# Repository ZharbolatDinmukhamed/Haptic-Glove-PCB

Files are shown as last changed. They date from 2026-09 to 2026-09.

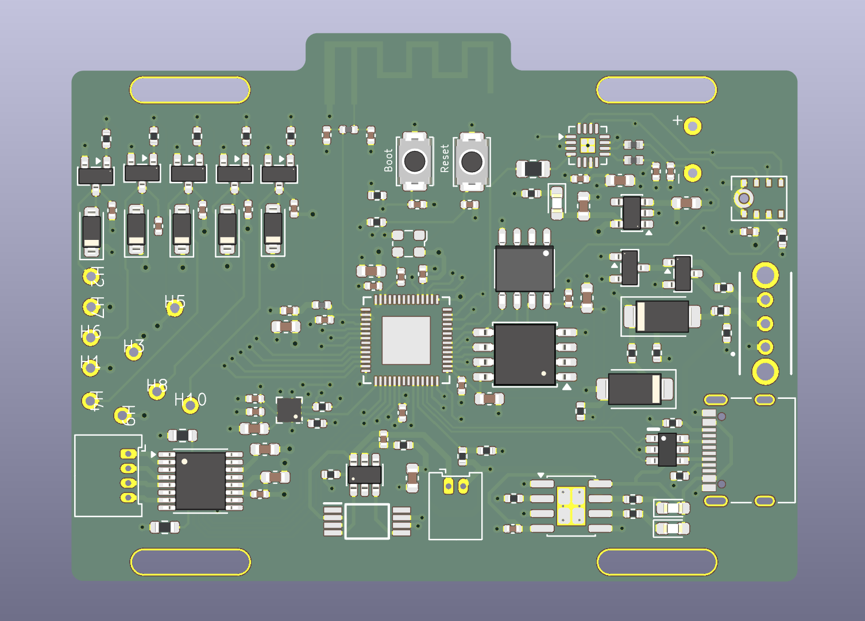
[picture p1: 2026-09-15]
Haptic Glove 3d view.png

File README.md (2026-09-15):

# Haptic Glove PCB

A wrist-mounted PCB for a haptic feedback glove, developed as part of my Research Assistantship at the Tactile Laboratory, Nazarbayev University.

## Overview
The board mounts on the wrist and drives 5 vibromotors, one per fingertip, delivering independent tactile feedback to each finger. It is designed to sit inside a glove, secured to the wrist via velcro straps threaded through slots in the board.

## Design Details
- **Board size:** 65mm x 50mm
- **Actuators:** 5x vibromotors (one per fingertip), each with a dedicated 3.3V power channel and signal channel
- **Driver components:** Capacitors and diodes placed near the board edge for each motor driver channel
- **Wrist-to-fingertip connection:** Discrete flexible wire harness (evaluated flex PCB / FPC, but chose a wire harness for flexibility and cost)
- **Mounting:** Component side faces outward (away from skin); board sits on the palm/volar side of the wrist inside the glove
- **Hand coverage:** Single-hand design

## Files
- `/schematic` — Schematic source files
- `/pcb` — PCB layout files
- `/gerbers` — Fabrication-ready Gerber files
- `/images` — Board renders and assembled photos
- `BOM.csv` — Bill of materials

## Tools
- [Your EDA tool — e.g. KiCad / Altium / Eagle]

## Status
[In progress / Fabricated & tested / etc. — update with current status]

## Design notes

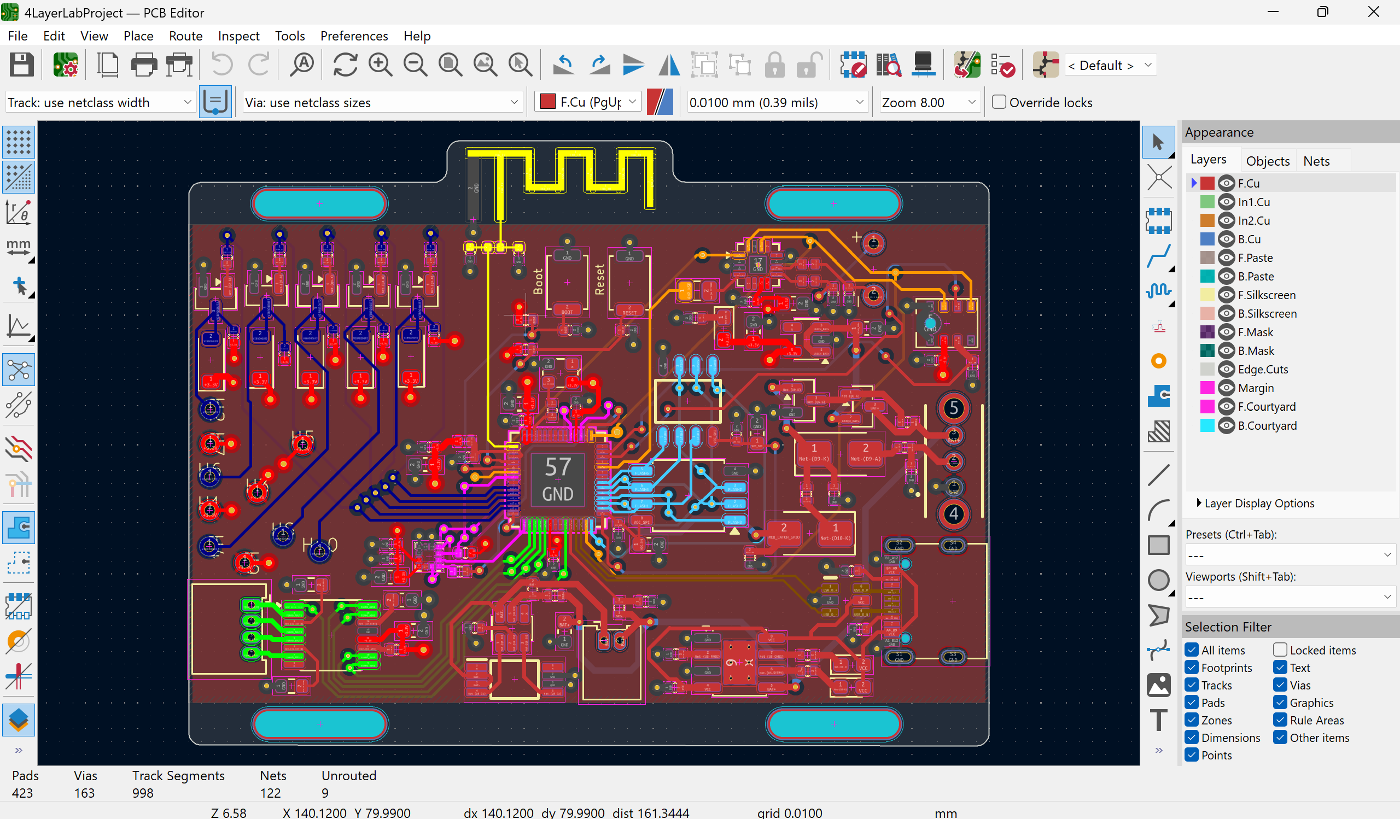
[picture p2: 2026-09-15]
Haptic Glove pcb view.png

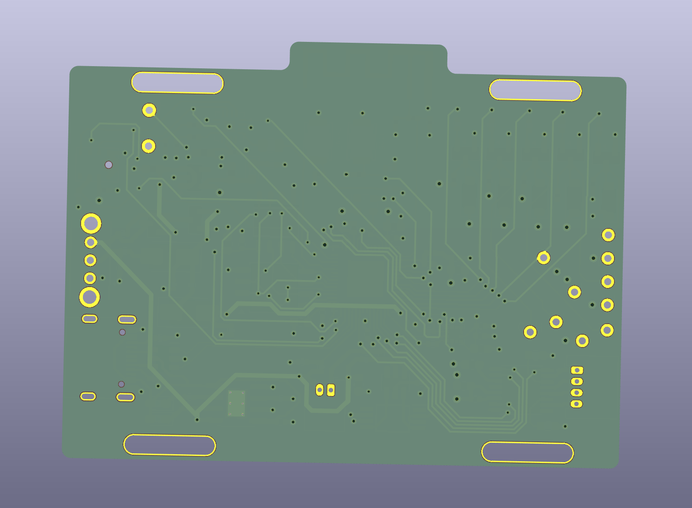
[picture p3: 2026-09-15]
Haptic Glove 3Dview.png

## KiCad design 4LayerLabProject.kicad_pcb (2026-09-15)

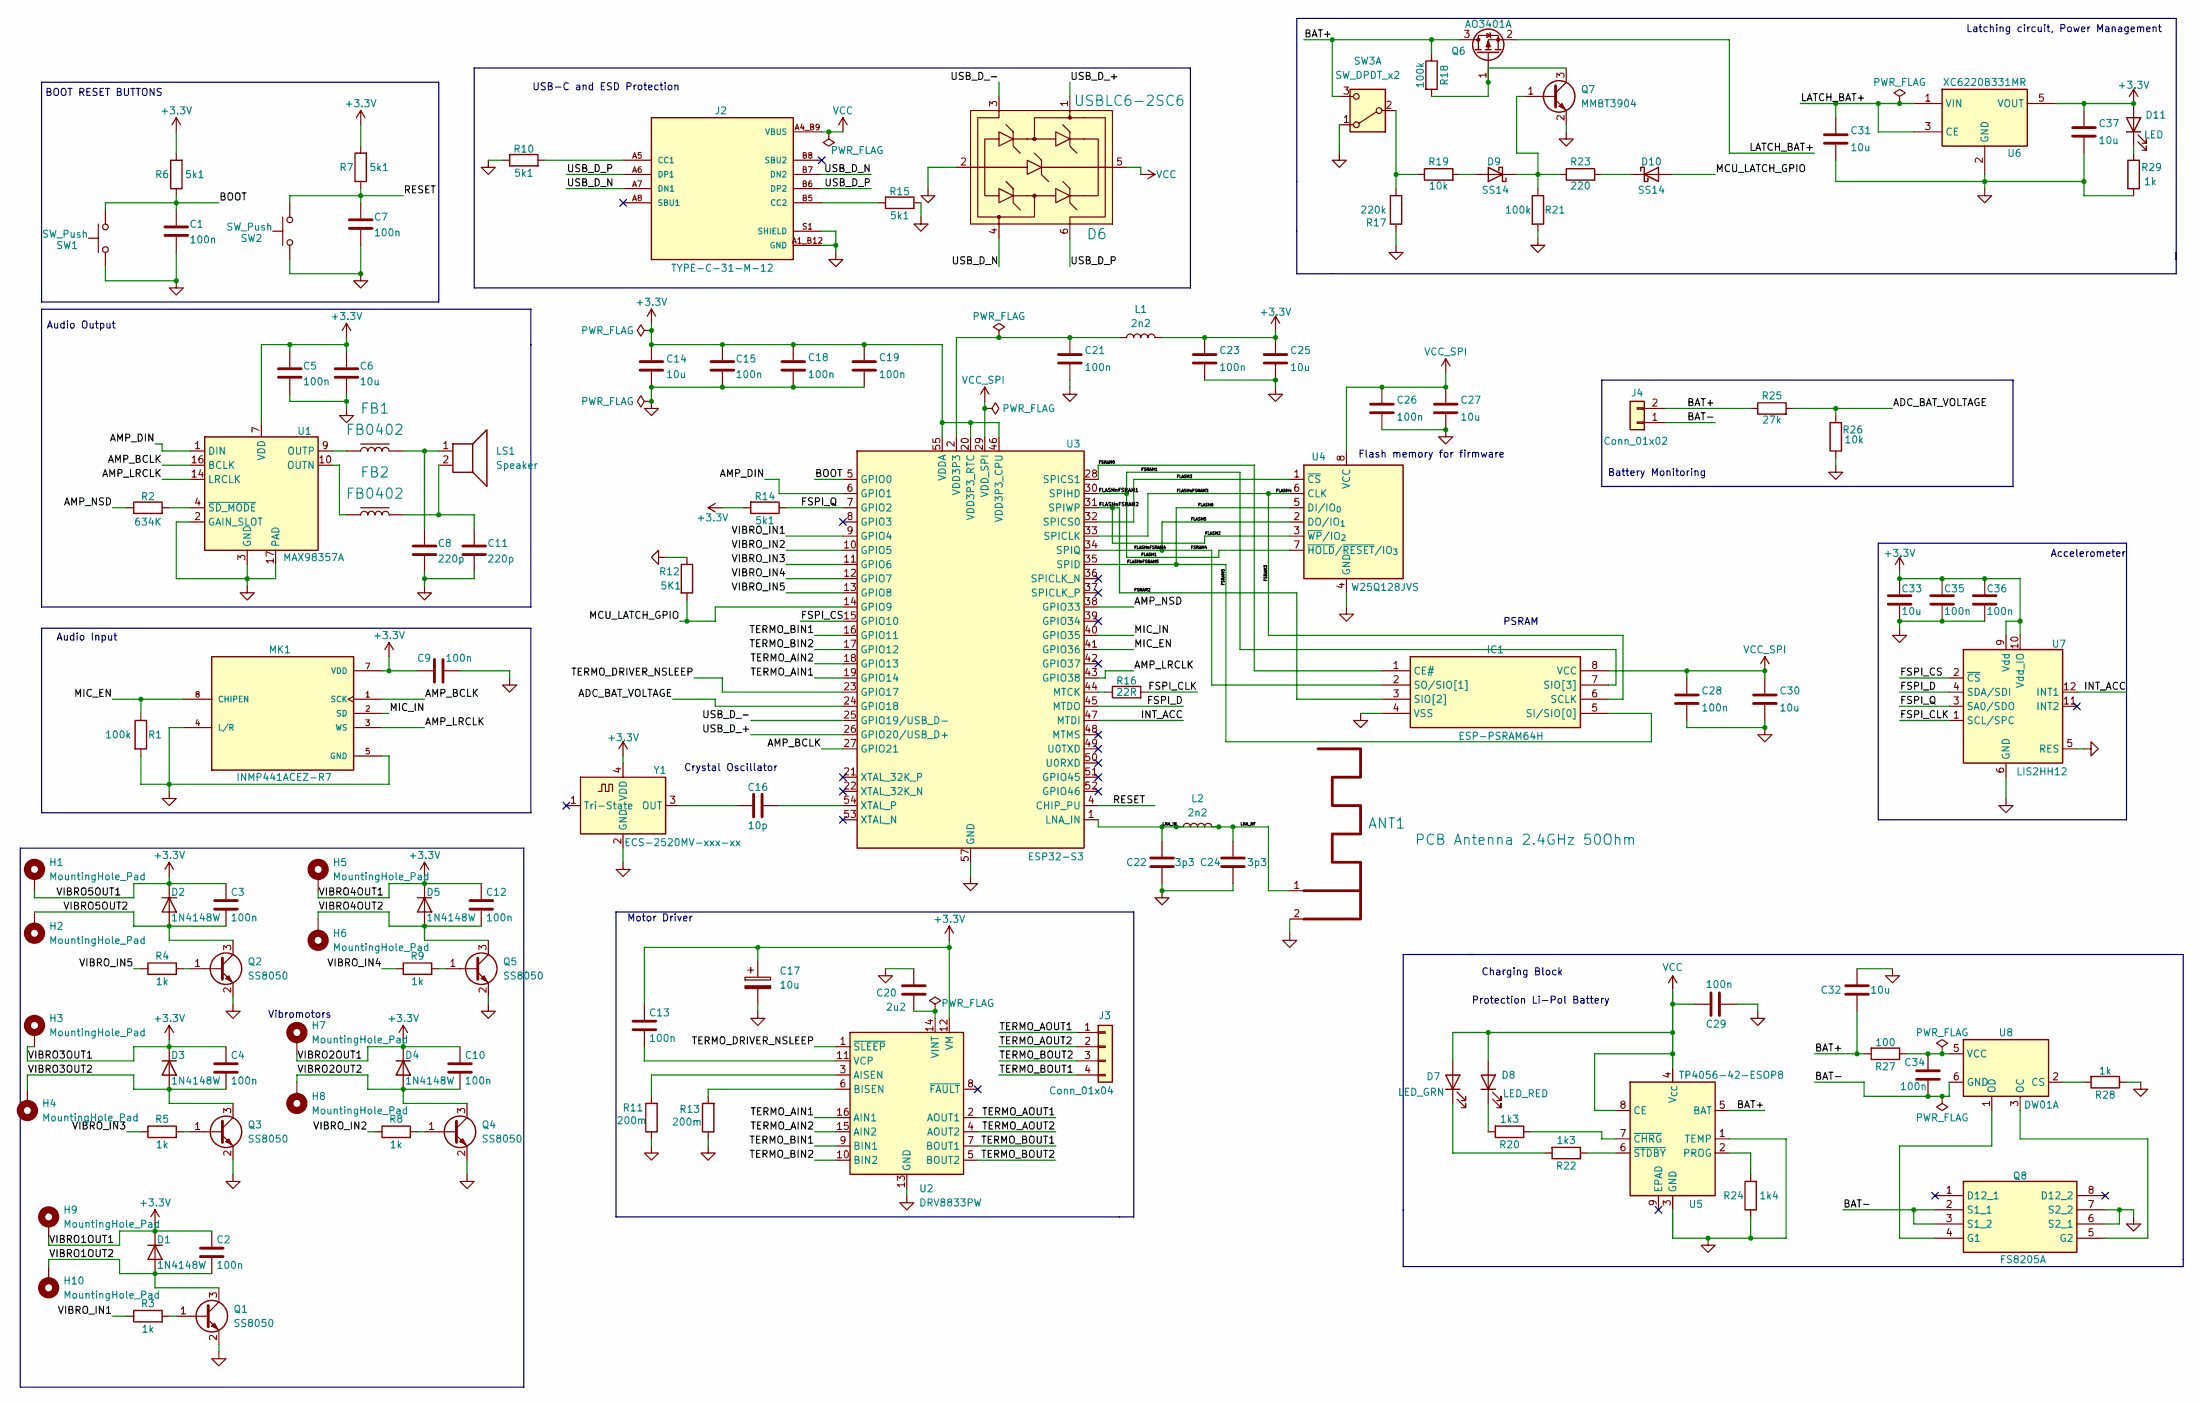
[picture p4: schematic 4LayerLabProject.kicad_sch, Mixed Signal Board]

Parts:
ANT1: PCB Antenna 2.4GHz 50Ohm; ANT_IFA_USB_2_4GHZ_50R
C1, C2, C3, C4, C5, C7, C9, C10, C12, C13, C15, C18, C19, C21, C23, C26, C28, C29, C34, C35, C36: 100n; C_0402_1005Metric
C6, C14, C17, C25, C27, C30, C31, C32, C33, C37: 10u; C_0603_1608Metric
C8, C11: 220p; C_0402_1005Metric
C16: 10p; C_0402_1005Metric
C20: 2u2; C_0603_1608Metric
C22, C24: 3p3; C_0402_1005Metric
D1, D2, D3, D4, D5: 1N4148W; D_SOD-123
D6: USBLC6-2SC6; SOT-23-6; Manufacturer Part Number USBLC6-2SC6
D7: LED_GRN; LED_0603_1608Metric_Pad1.05x0.95mm_HandSolder
D8: LED_RED; LED_0603_1608Metric_Pad1.05x0.95mm_HandSolder
D9, D10: SS14; D_SMA
D11: LED; LED_0603_1608Metric_Pad1.05x0.95mm_HandSolder
FB1, FB2: FB0402; FB_0402; Manufacturer Part Number *; LCSC *
H1, H2, H3, H4, H5, H6, H7, H8, H9, H10: MountingHole_Pad; tht_pad
IC1: ESP-PSRAM64H; SOIC127P600X175-8N; Manufacturer_Part_Number ESP-PSRAM64H
J2: TYPE-C-31-M-12; HRO_TYPE-C-31-M-12; PARTREV 2020.12.08
J3: Conn_01x04; Molex_PicoBlade_53048-0410_1x04_P1.25mm_Horizontal
J4: Conn_01x02; Molex_PicoBlade_53048-0210_1x02_P1.25mm_Horizontal
L1, L2: 2n2; L_0402_1005Metric
LS1: Speaker; Untitled_1
MK1: INMP441ACEZ-R7; MIC_INMP441ACEZ-R7; PARTREV 1.1
Q1, Q2, Q3, Q4, Q5: SS8050; SOT-23
Q6: AO3401A; SOT-23
Q7: MMBT3904; SOT-23
Q8: FS8205A; SOP65P640X120-8N; Manufacturer_Part_Number FS8205A
R1, R18, R21: 100k; R_0402_1005Metric
R2: 634K; R_0805_2012Metric
R3, R4, R5, R8, R9, R28, R29: 1k; R_0402_1005Metric
R6, R7, R10, R14, R15: 5k1; R_0402_1005Metric
R11, R13: 200m; R_0603_1608Metric
R12: 5K1; R_0402_1005Metric
R16: 22R; R_0402_1005Metric
R17: 220k; R_0402_1005Metric
R19, R26: 10k; R_0402_1005Metric
R20, R22: 1k3; R_0402_1005Metric
R23: 220; R_0402_1005Metric
R24: 1k4; R_0402_1005Metric
R25: 27k; R_0402_1005Metric
R27: 100; R_0402_1005Metric
SW1, SW2: SW_Push; SW_Push_SPST_NO_Alps_SKRK
SW3: SW_DPDT_x2; OS102011MA1QN1
U1: MAX98357A; TQFN-16-1EP_3x3mm_P0.5mm_EP1.23x1.23mm
U2: DRV8833PW; TSSOP-16_4.4x5mm_P0.65mm
U3: ESP32-S3; QFN56_7X7_EXP
U4: W25Q128JVS; SOIC-8_5.3x5.3mm_P1.27mm
U5: TP4056-42-ESOP8; SOIC-8-1EP_3.9x4.9mm_P1.27mm_EP2.41x3.3mm_ThermalVias
U6: XC6220B331MR; SOT-23-5
U7: LIS2HH12; LGA-12_2x2mm_P0.5mm
U8: DW01A; SOT-23-6
Y1: ECS-2520MV-xxx-xx; Oscillator_SMD_ECS_2520MV-xxx-xx-4Pin_2.5x2.0mm

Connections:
+3.3V: C2.1, C3.1, C4.1, C5.1, C6.1, C9.1, C10.1, C12.1, C13.1, C14.1, C15.1, C17.1, C18.1, C19.1, C23.1, C25.1, C33.1, C35.1, C36.1, C37.1, D1.1 (K), D2.1 (K), D3.1 (K), D4.1 (K), D5.1 (K), D11.2 (A), H1.1 (1_1), H3.1 (1_1), H5.1 (1_1), H7.1 (1_1), H9.1 (1_1), L1.2, MK1.7 (VDD), R6.2, R7.2, R14.2, U1.7 (VDD), U1.8 (VDD), U2.12 (VM), U3.20 (VDD3P3_RTC), U3.46 (VDD3P3_CPU), U3.55 (VDDA), U3.56 (VDDA), U6.5 (VOUT), U7.9 (Vdd), U7.10 (Vdd_IO), Y1.4 (VDD)
/ADC_BAT_VOLTAGE: R25.2, R26.2, U3.24 (GPIO18)
/AMP_BCLK: MK1.1 (SCK), U1.16 (BCLK), U3.27 (GPIO21)
/AMP_DIN: U1.1 (DIN), U3.6 (GPIO1)
/AMP_LRCLK: MK1.3 (WS), U1.14 (LRCLK), U3.43 (GPIO38)
/AMP_NSD: R2.1, U3.38 (GPIO33)
/BAT+: C32.2, J4.2, Q6.3 (D), R18.1, R25.1, R27.2, SW3.3 (C), U5.5 (BAT)
/BAT-: C34.2, J4.1, Q8.2 (S1_1), Q8.3 (S1_2), U8.6 (GND)
/BOOT: C1.1, R6.1, SW1.2, U3.5 (GPIO0)
/FLASH1: IC1.7 (SIO[3]), U3.30 (SPIHD), U4.7 (~HOLD/~RESET/IO_{3})
/FLASH2: IC1.3 (SIO[2]), U3.31 (SPIWP), U4.3 (~WP/IO_{2})
/FLASH3: U3.32 (SPICS0), U4.1 (~CS)
/FLASH4: IC1.6 (SCLK), U3.33 (SPICLK), U4.6 (CLK)
/FLASH5: IC1.2 (SO/SIO[1]), U3.34 (SPIQ), U4.2 (DO/IO_{1})
/FLASH6: IC1.5 (SI/SIO[0]), U3.35 (SPID), U4.5 (DI/IO_{0})
/FSPI_CLK: R16.2, U7.1 (SCL/SPC)
/FSPI_CS: U3.15 (GPIO10), U7.2 (~CS)
/FSPI_D: U3.45 (MTDO), U7.4 (SDA/SDI)
/FSPI_Q: R14.1, U3.7 (GPIO2), U7.3 (SA0/SDO)
/FSRAM0: IC1.1 (CE#), U3.28 (SPICS1)
/INT_ACC: U3.47 (MTDI), U7.12 (INT1)
/LATCH_BAT+: C31.1, Q6.2 (S), U6.1 (VIN), U6.3 (CE)
/LNA_IN: ANT1.1 (RF), C22.2, C24.2, L2.1, L2.2, U3.1 (LNA_IN)
/MCU_LATCH_GPIO: D10.2 (A), R12.2, U3.14 (GPIO9)
/MIC_EN: MK1.8 (CHIPEN), R1.1, U3.41 (GPIO36)
/MIC_IN: MK1.2 (SD), U3.40 (GPIO35)
/RESET: C7.1, R7.1, SW2.2, U3.4 (CHIP_PU)
/TERMO_AIN1: U2.16 (AIN1), U3.19 (GPIO14)
/TERMO_AIN2: U2.15 (AIN2), U3.18 (GPIO13)
/TERMO_AOUT1: J3.1, U2.2 (AOUT1)
/TERMO_AOUT2: J3.2, U2.4 (AOUT2)
/TERMO_BIN1: U2.9 (BIN1), U3.16 (GPIO11)
/TERMO_BIN2: U2.10 (BIN2), U3.17 (GPIO12)
/TERMO_BOUT1: J3.4, U2.7 (BOUT1)
/TERMO_BOUT2: J3.3, U2.5 (BOUT2)
/TERMO_DRIVER_NSLEEP: U2.1 (~SLEEP), U3.23 (GPIO17)
/USB_D_+: D6.1 (IO1), U3.26 (GPIO20/USB_D+)
/USB_D_-: D6.3 (IO2), U3.25 (GPIO19/USB_D-)
/USB_D_N: D6.4 (IO2), J2.A7 (DN1), J2.B7 (DN2)
/USB_D_P: D6.6 (IO1), J2.A6 (DP1), J2.B6 (DP2)
/VIBRO1OUT2: C2.2, D1.2 (A), H10.1 (1_1), Q1.3 (C)
/VIBRO2OUT2: C10.2, D4.2 (A), H8.1 (1_1), Q4.3 (C)
/VIBRO3OUT2: C4.2, D3.2 (A), H4.1 (1_1), Q3.3 (C)
/VIBRO4OUT2: C12.2, D5.2 (A), H6.1 (1_1), Q5.3 (C)
/VIBRO5OUT2: C3.2, D2.2 (A), H2.1 (1_1), Q2.3 (C)
/VIBRO_IN1: R3.1, U3.9 (GPIO4)
/VIBRO_IN2: R8.1, U3.10 (GPIO5)
/VIBRO_IN3: R5.1, U3.11 (GPIO6)
/VIBRO_IN4: R9.1, U3.12 (GPIO7)
/VIBRO_IN5: R4.1, U3.13 (GPIO8)
GND: ANT1.2 (GND), C1.2, C5.2, C6.2, C7.2, C8.2, C9.2, C11.2, C14.2, C15.2, C17.2, C18.2, C19.2, C20.1, C21.2, C22.1, C23.2, C24.1, C25.2, C26.2, C27.2, C28.2, C29.1, C30.2, C31.2, C32.1, C33.2, C35.2, C36.2, C37.2, D6.2 (GND), IC1.4 (VSS), J2.A1_B12 (GND), J2.B1_A12 (GND), J2.S1 (SHIELD), J2.S2 (SHIELD), J2.S3 (SHIELD), J2.S4 (SHIELD), MK1.4 (L/R), MK1.5 (GND), MK1.6 (GND), MK1.9 (GND), Q1.2 (E), Q2.2 (E), Q3.2 (E), Q4.2 (E), Q5.2 (E), Q7.2 (E), Q8.6 (S2_1), Q8.7 (S2_2), R1.2, R10.1, R11.1, R12.1, R13.1, R15.2, R17.2, R21.2, R24.1, R26.1, R28.1, R29.2, SW1.1, SW2.1, SW3.1 (A), U1.2 (GAIN_SLOT), U1.3 (GND), U1.11 (GND), U1.15 (GND), U1.17 (PAD), U2.13 (GND), U3.57 (GND), U4.4 (GND), U5.1 (TEMP), U5.3 (GND), U6.2 (GND), U7.5 (RES), U7.6 (GND), U7.7 (GND), U7.8 (GND), Y1.2 (GND)
unnamed: C8.1, FB1.2, LS1.1
unnamed: C11.1, FB2.2, LS1.2
unnamed: C21.1, L1.1, U3.2 (VDD3P3), U3.3 (VDD3P3)
unnamed: D7.1 (K), R22.2
unnamed: D8.1 (K), R20.2
unnamed: D9.2 (A), R19.2
unnamed: D9.1 (K), Q7.1 (B), R21.1, R23.1
unnamed: D10.1 (K), R23.2
unnamed: D11.1 (K), R29.1
unnamed: J2.A5 (CC1), R10.2
unnamed: J2.B5 (CC2), R15.1
unnamed: Q1.1 (B), R3.2
unnamed: Q2.1 (B), R4.2
unnamed: Q3.1 (B), R5.2
unnamed: Q4.1 (B), R8.2
unnamed: Q5.1 (B), R9.2
unnamed: Q6.1 (G), Q7.3 (C), R18.2
unnamed: Q8.4 (G1), U8.1 (OD)
unnamed: Q8.5 (G2), U8.3 (OC)
unnamed: R17.1, R19.1, SW3.2 (B)
unnamed: FB2.1, U1.10 (OUTN)
unnamed: FB1.1, U1.9 (OUTP)
unnamed: R2.2, U1.4 (~SD_MODE)
unnamed: R11.2, U2.3 (AISEN)
unnamed: R13.2, U2.6 (BISEN)
unnamed: C13.2, U2.11 (VCP)
unnamed: C20.2, U2.14 (VINT)
unnamed: R16.1, U3.44 (MTCK)
unnamed: C16.2, U3.54 (XTAL_P)
unnamed: R24.2, U5.2 (PROG)
unnamed: R20.1, U5.7 (~CHRG)
unnamed: R22.1, U5.6 (~STDBY)
unnamed: R28.2, U8.2 (CS)
unnamed: C34.1, R27.1, U8.5 (VCC)
unnamed: C16.1, Y1.3 (OUT)
VCC: C29.2, D6.5 (VBUS), D7.2 (A), D8.2 (A), J2.A4_B9 (VBUS), J2.B4_A9 (VBUS), U5.4 (V_{CC}), U5.8 (CE)
VCC_SPI: C26.1, C27.1, C28.1, C30.1, IC1.8 (VCC), U3.29 (VDD_SPI), U4.8 (VCC)

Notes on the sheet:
Accelerometer
Charging Block
Battery Monitoring
USB-C and ESD Protection
Vibromotors
BOOT RESET BUTTONS
Flash memory for firmware
Crystal Oscillator
Audio Input
PSRAM
Latching circuit, Power Management
Motor Driver
Audio Output
Protection Li-Pol Battery

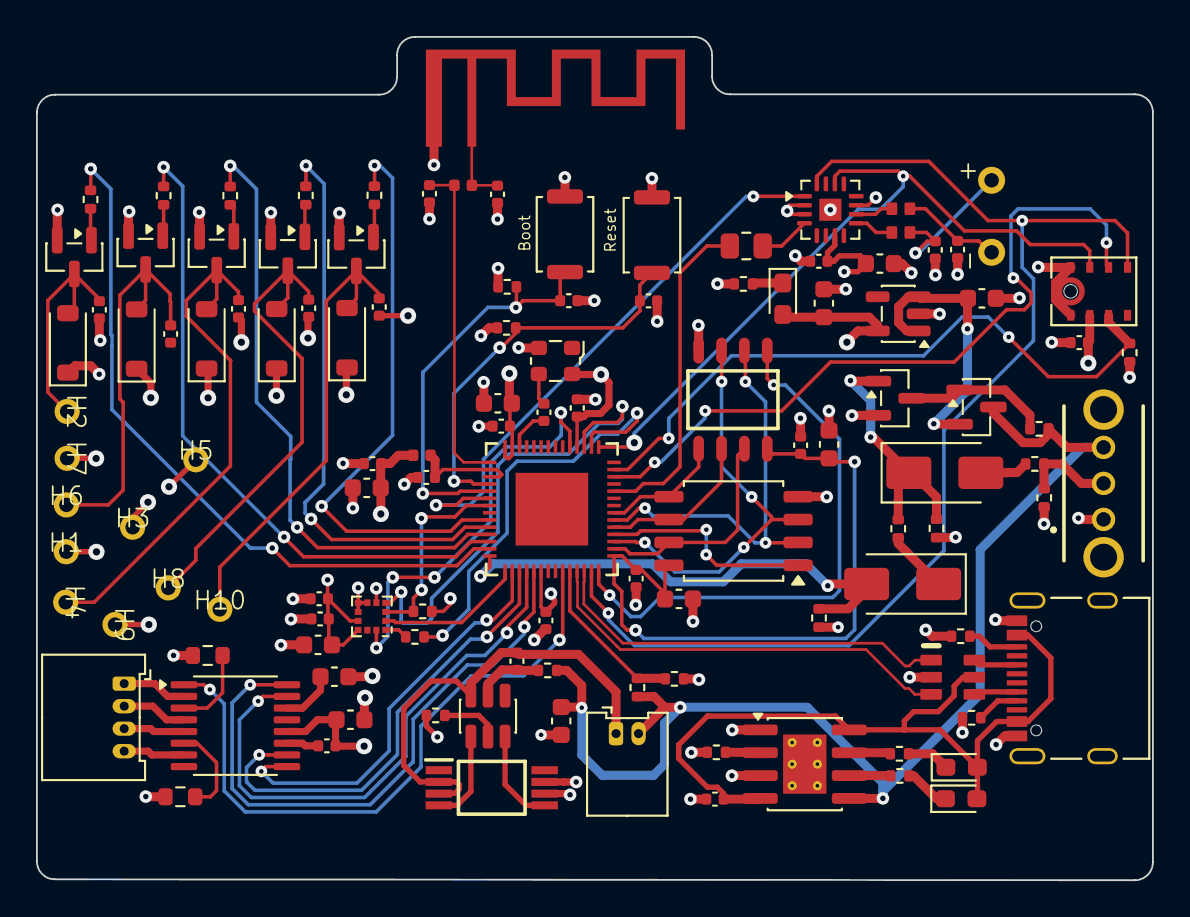
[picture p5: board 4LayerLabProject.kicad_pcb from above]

Board: 4 copper layers, 62.0 x 46.9 mm, 118 parts (0 on the bottom side), 88 nets.
